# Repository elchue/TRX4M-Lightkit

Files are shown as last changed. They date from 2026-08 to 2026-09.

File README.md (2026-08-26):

## 🚙 Traxxas TRX-4M Custom Light Controller
 

Ein maßgeschneidertes, intelligentes Steuergerät (basierend auf dem **ESP32-C6**), um das **originale Traxxas TRX-4M Pro Scale Lichtkit (inkl. Lightbar)** mit 3rd-Party Fernsteuerungen (wie Flysky Noble NB4, Radiomaster, Futaba etc.) und Aftermarket-ESCs weiterverwenden zu können!

Wer seinen TRX-4M auf Brushless (z. B. Furitek) oder eine professionelle Funke umbaut, verliert normalerweise die Funktion des originalen Traxxas-Lichtsets, da dieses fest an die Traxxas ECM-2.5 Einheit gebunden ist. Dieses Projekt ersetzt die Traxxas-Elektronik als "Gehirn" für die Lichter und wertet das System mit smarten Features, Web-Konfiguration und Telemetrie-ähnlicher Auswertung extrem auf.

## ✨ Warum dieses Projekt?
Das originale TRX-4M Lichtkit nutzt adressierbare LEDs (ähnlich dem WS2812-Protokoll), die über eine serielle Datenleitung angesteuert werden. Wie genau wir die proprietären Signale entschlüsselt haben, kannst du in unserer detaillierten [Hardware & Protokoll Dokumentation (Reverse Engineering)](/docs/README.md) nachlesen.

Dieses Modul liest das Signal deines neuen Empfängers aus, berechnet die Fahrphysik und übersetzt sie in Echtzeit für das Traxxas-Lichtset. Du musst nichts abrüsten oder neu verkabeln – das Modul klinkt sich einfach als Übersetzer dazwischen!

## 🚀 Features
* **Multi-Protokoll für 3rd-Party Empfänger:** Unterstützt SBUS, iBUS und klassisches PPM. Ideal für Micro-Empfänger.
* **Smartphone Web-Interface:** Eigener WLAN-Access-Point zur einfachen Konfiguration direkt am Fahrzeug (Deutsch & Englisch). Kein PC auf dem Trail nötig!
* **Perfekte Anpassung an die Funke:**
  * **Volles Channel-Mapping:** Weise Funktionen wie Hauptlicht, Zusatzscheinwerfer und Blinker völlig frei beliebigen Empfängerkanälen zu.
  * **Auto-Trim-Funktion:** Ein Klick im Web-Interface und das Modul speichert den mechanischen Lenk-Offset (Nullpunkt) deiner Funke.
  * **Reverse-Schalter:** Die Laufrichtung jedes Kanals lässt sich direkt in der Software umkehren.
* **Erweiterte Blinker- & Licht-Logik:**
  * **Smart Auto-Cancel:** Blinker schaltet sich wie beim echten Auto ab, wenn du aus der Kurve lenkst.
  * **Blinker-Styles:** Wähle das optische Design (Classic, Soft-Off (Mazda), Soft-On (BMW), Retro Glühlampe).
  * **Regionale Licht-Profile (EU/US):** Verwandle die Optik deines Scalers mit einem Klick:
    * *EU-Style:* Klassisch getrennte Blinker (gelb) und Bremslichter (rot).
    * *US-Style Front:* Vordere Blinker glimmen dauerhaft gedimmt als orange Sidemarker (Standlicht) und pulsieren beim Blinken.
    * *US-Style Komplett:* Front-Sidemarker kombiniert mit typisch amerikanischem Heck (das rote Bremslicht blinkt im Takt, die gelben Blinker bleiben deaktiviert).
* **Adaptives Bremslicht (ESS):** Erkennt echte Vollbremsungen über den Gashebel und lässt das Bremslicht realistisch flackern. Danach schaltet sich automatisch der Warnblinker ein.
* **ESC-Kompatibilität & Fahrlogik:** Drei wählbare Profile für die perfekte Erkennung von Bremse und Rückfahrlicht:
  * *Standard:* Klassischer RC-Regler (Doppelklick für Rückwärts).
  * *Crawler (FOC):* Drag-Brake Erkennung und direkter Übergang in den Rückwärtsgang.
  * *Real-Car (Getriebe):* Manuelle Gangschaltung (Vorwärts / Rückwärts) über einen separaten AUX-Kanal für den ultimativen Scale-Realismus.
* **Standby & Parklicht:** Dimmt die Scheinwerfer nach definierter Inaktivität automatisch ab, um Strom zu sparen und Hitzestau zu vermeiden. Generelle Master-Helligkeit im Web-UI einstellbar.

## 🛠 Hardware & Verkabelung
Das Projekt läuft auf einem **Seeed Studio XIAO ESP32-C6** (oder ähnlichen, kompakten ESP32-Boards), da dieser klein genug ist, um problemlos in den TRX-4M zu passen.
* **Eingang:** Der ESP32 wird per 3-Pin-Kabel mit dem Empfänger verbunden (Strom, GND, Signal-Pin für SBUS/iBUS/PPM).
* **Ausgänge (2-Kanal System):** Die Ansteuerung der Traxxas-LEDs erfolgt über zwei getrennte Datenleitungen am ESP32.
  * **Kanal 1 (Main):** Übernimmt die komplette Basis-Fahrzeugbeleuchtung (Scheinwerfer, Rücklichter, Blinker).
  * **Kanal 2 (Aux):** Ist exklusiv für Zusatzscheinwerfer (z. B. Lightbars oder Roof-Lights) reserviert und lässt sich separat schalten.

*(Detaillierte Pin-Belegung und Schaltpläne für den Anschluss des Traxxas-Kabelbaums findest du im Wiki / in den Code-Kommentaren).*

## 💻 Installation (PlatformIO)
1. Repository klonen: 
    ``` bash
    git clone https://github.com/DEIN_NAME/trx4m-light-controller.git
    ```
2. Ordner in **VS Code** (mit PlatformIO) öffnen.
3. ESP32-C6 über USB-C anschließen.
4. Auf "Upload" klicken – PlatformIO kompiliert den Code und flasht den Chip automatisch.

## 📱 Konfiguration im Fahrzeug
1. TRX-4M einschalten. Der ESP32 öffnet ein WLAN-Netzwerk (z.B. ProScale-Config).
2. Smartphone verbinden und [http://192.168.4.1](http://192.168.4.1) im Browser öffnen.
3. Kanäle zuweisen, Blinker-Verhalten wählen und ggf. die Lenkung über den "Auto-Trim"-Button exakt nullen.
4. Speichern, Neustart abwarten – fertig für den Trail!

## 📄 Lizenz
Dieses Projekt ist unter der GNU General Public License v3.0 (GPLv3) lizenziert. Der Code ist Open Source. Details siehe LICENSE-Datei.

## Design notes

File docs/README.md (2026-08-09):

# TRX-4M Pro Scale Lichtsystem - Reverse Engineering

Dieses Repository enthält die Hardware-Zuordnung und Logik, um das proprietäre Traxxas TRX-4M Pro Scale Lichtsystem (Light Kit) sowie das originale Zubehör (Anhänger-Beleuchtung, Lightbars) mit eigenen Mikrocontrollern (z. B. ESP32, Arduino, SAMD21) und Standard-RC-Empfängern (wie Flysky iBUS) zu steuern.

## Hardware-Aufbau und das Y-Kabel-Prinzip

Das Traxxas Lichtkabel basiert technisch auf dem **WS2811/WS2812 (NeoPixel)** Protokoll. Anstatt jedoch echte RGB-LEDs zu verbauen, die ihre Farbe wechseln können, nutzt Traxxas unsichtbare Controller-Chips auf den Platinen, die das Signal empfangen. An die drei Farbausgänge (Rot, Grün, Blau) eines einzelnen Chips hat Traxxas hardwareseitig **drei verschiedene, einfarbige LEDs** gelötet. Ein Befehl für "100% Rot" schaltet also keine rote Farbe ein, sondern aktiviert einen spezifischen Funktionsausgang (z. B. den Blinker).

### Besonderheit: Die Verkabelung am ECM-2.5
Am originalen Traxxas **ECM-2.5** (Empfänger/ESC-Einheit) wird das Datensignal teilweise über physische Y-Kabel aufgeteilt:
1. **Haupt-Lichtkit:** Steuert die vier Ecken des Fahrzeugs.
2. **Zusatzscheinwerfer:** (Lightbar + Kühlergrill) Hängen an einem Y-Kabel und lesen denselben Datenstrom wie das vordere linke Abblendlicht mit.
3. **Anhänger:** Hängt ebenfalls an einem Y-Kabel. Die Chips im Anhänger sind so konfiguriert, dass sie synchron auf die Daten der hinteren Fahrzeugbeleuchtung (Chip 2 und 3) reagieren.

## Die LED-Matrix (Hardware Mapping)

Das gesamte System lässt sich im Code wie ein Strang aus **4 NeoPixel-Chips** (Index 0 bis 3) ansteuern. Die Helligkeit der Lampen kann über PWM-Werte (0 = Aus, 255 = Hell) stufenlos gedimmt werden.

| Chip Index | Farb-Kanal im Code | Funktion am Fahrzeug | Funktion am Anhänger |
| :--- | :--- | :--- | :--- |
| **Chip 0** | Rot | Blinker vorne Links | - |
| **Chip 0** | Grün | Tagfahrlicht Links | - |
| **Chip 0** | Blau | Abblendlicht Links + Zusatzscheinwerfer* | - |
| **Chip 1** | Rot | Blinker vorne Rechts | - |
| **Chip 1** | Grün | Tagfahrlicht Rechts | - |
| **Chip 1** | Blau | Abblendlicht Rechts | - |
| **Chip 2** | Rot | Blinker hinten Rechts | Blinker Rechts (rot) |
| **Chip 2** | Grün | Rückfahrlicht Rechts (weiß) | Rückfahrlicht Rechts |
| **Chip 2** | Blau | Rücklicht / Bremslicht Rechts | Bremslicht Rechts |
| **Chip 3** | Rot | Blinker hinten Links | Blinker Links (rot) |
| **Chip 3** | Grün | Rückfahrlicht Links (weiß) | Rückfahrlicht Links |
| **Chip 3** | Blau | Rücklicht / Bremslicht Links | Bremslicht Links |

*\*Hinweis zu den Zusatzscheinwerfern: Da diese über ein Y-Kabel fest mit dem blauen Kanal von Chip 0 gekoppelt sind, leuchten sie im Werkszustand immer synchron mit dem Abblendlicht auf.*

## Modding-Potenzial: Unabhängige Steuerung

Da das Traxxas ECM-2.5 die Stränge per Y-Kabel zusammenschließt, sind Anhänger und Lightbar im Originalzustand an die Hauptbeleuchtung gekoppelt. 

Wenn man das System mit einem eigenen Mikrocontroller steuert, können die Y-Kabel entfernt und die Komponenten an **separate GPIO-Pins** des Mikrocontrollers (z. B. 3 getrennte NeoPixel-Instanzen in der Software) angeschlossen werden. 
Dies ermöglicht völlig neue Funktionen, wie zum Beispiel:
* Zusatzscheinwerfer (Dach/Grill) unabhängig vom Abblendlicht per Fernsteuerung schalten.
* Anhängerbeleuchtung abweichend vom Zugfahrzeug steuern (z. B. Warnblinker nur am Anhänger).

## Programmierung (Beispiel)

Zur Ansteuerung kann jede handelsübliche Bibliothek für adressierbare LEDs genutzt werden (z. B. `Adafruit_NeoPixel` oder `FastLED`).

Um das Bremslicht hinten links am Fahrzeug (und zeitgleich am Anhänger, falls per Y-Kabel verbunden) auf 100% Helligkeit einzuschalten, wird der "Blaue" Kanal von Chip 3 angesteuert:
`strip.setPixelColor(3, 0, 0, 255)`

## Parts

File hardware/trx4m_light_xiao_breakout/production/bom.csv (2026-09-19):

Designator | Footprint | Quantity | Value | LCSC Part #
C1, C4 | CP_EIA-7343-20_Kemet-V | 2 | 470µF | C49332972
C2, C5 | 0805 | 2 | 100nF | C28233
C3 | 0805 | 1 | 10µF | C15850
J1, J2, J3 | PinHeader_1x03_P2.54mm_Vertical | 3 | Conn_01x03
L1 | L_Ferrocore_DLG-0403 | 1 | 4.7µH | C2879693
R1 | 0805 | 1 | 330R | C17630
R2 | 0805 | 1 | R330 | C17630
SW1 | SW_Tactile_SPST_NO_Straight_CK_PTS636Sx25SMTRLFS | 1 | SW_Push | C2689642
U1 | XIAO-14P-Add-On | 1 | XIAO-ESP32-C6-SMD
U2 | VSSOP-8_2.3x2mm_P0.5mm | 1 | 74LVC2T45DC | C15741
U3 | TSOT-23-6 | 1 | AP63205WU | C2071056

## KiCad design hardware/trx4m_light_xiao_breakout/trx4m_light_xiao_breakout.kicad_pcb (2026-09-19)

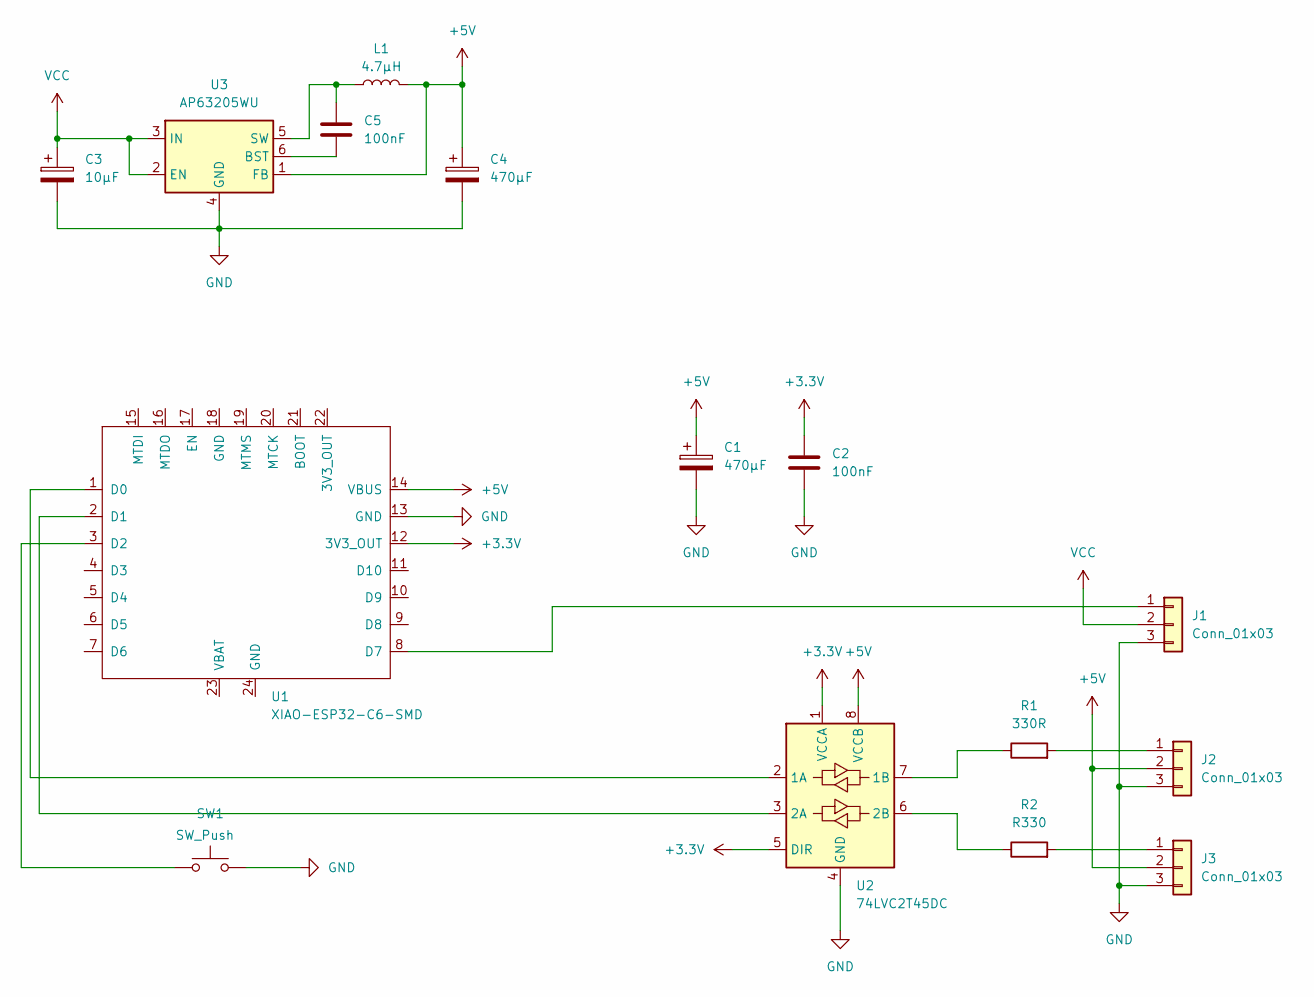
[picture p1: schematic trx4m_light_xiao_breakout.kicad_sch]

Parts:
C1, C4: 470µF; CP_EIA-7343-20_Kemet-V; LCSC C49332972
C2, C5: 100nF; C_0805_2012Metric; LCSC C28233
C3: 10µF; C_0805_2012Metric; LCSC C15850
J1, J2, J3: Conn_01x03; PinHeader_1x03_P2.54mm_Vertical
L1: 4.7µH; L_Ferrocore_DLG-0403; LCSC C2879693
R1: 330R; R_0805_2012Metric; LCSC C17630
R2: R330; R_0805_2012Metric; LCSC C17630
SW1: SW_Push; SW_Tactile_SPST_NO_Straight_CK_PTS636Sx25SMTRLFS; LCSC C2689642
U1: XIAO-ESP32-C6-SMD; XIAO-14P-Add-On
U2: 74LVC2T45DC; VSSOP-8_2.3x2mm_P0.5mm; LCSC C15741
U3: AP63205WU; TSOT-23-6; LCSC C2071056

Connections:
+3.3V: C2.1, U1.12 (3V3_OUT), U2.1 (VCCA), U2.5 (DIR)
+5V: C1.1, C4.1, J2.2, J3.2, L1.2, U1.14 (VBUS), U2.8 (VCCB), U3.1 (FB)
GND: C1.2, C2.2, C3.2, C4.2, J1.3, J2.3, J3.3, SW1.2, U1.13 (GND), U2.4 (GND), U3.4 (GND)
unnamed: J1.1, U1.8 (D7)
unnamed: J2.1, R1.2
unnamed: J3.1, R2.2
unnamed: U1.1 (D0), U2.2 (1A)
unnamed: U1.2 (D1), U2.3 (2A)
unnamed: SW1.1, U1.3 (D2)
unnamed: R1.1, U2.7 (1B)
unnamed: R2.1, U2.6 (2B)
unnamed: C5.2, U3.6 (BST)
unnamed: C5.1, L1.1, U3.5 (SW)
VCC: C3.1, J1.2, U3.2 (EN), U3.3 (IN)

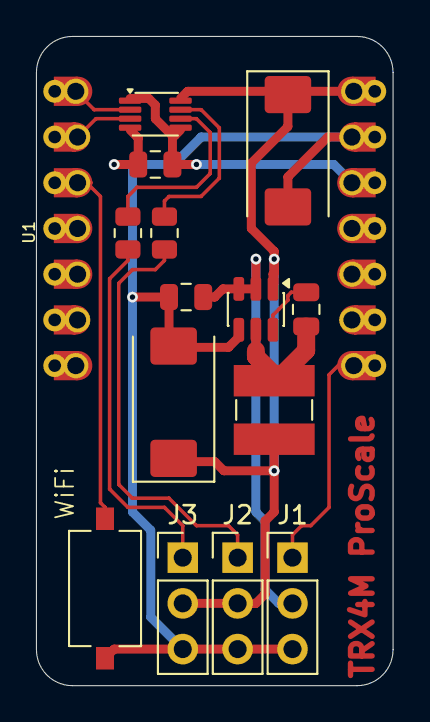
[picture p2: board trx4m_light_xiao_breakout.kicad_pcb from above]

Board: 2 copper layers, 19.8 x 36.1 mm, 15 parts (0 on the bottom side), 14 nets.

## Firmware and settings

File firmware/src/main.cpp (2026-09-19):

#include <Arduino.h>
#include "modules/globals.h"
#include "modules/rc_input.h"
#include "modules/web_config.h"
#include "modules/led_output.h"
#include "modules/drive_logic.h"

// ==========================================
// GLOBALE VARIABLEN DEKLARATION (Hier erwachen sie zum Leben)
// ==========================================
Config cfg;
uint16_t rc_channels[14] = {1500, 1500, 1500, 1500, 1500, 1500, 1500, 1500, 1500, 1500, 1500, 1500, 1500, 1500};
unsigned long last_rc_time = 0;
bool signalValid = false;

bool configMode = false;
volatile bool clientDisconnected = false;
unsigned long letzteBewegung = 0;

Adafruit_NeoPixel stripMain(NUM_LEDS_MAIN, PIN_LED_MAIN, NEO_RGB + NEO_KHZ800);
Adafruit_NeoPixel stripAux(NUM_LEDS_AUX, PIN_LED_AUX, NEO_RGB + NEO_KHZ800);

// ==========================================
// STATUS / HEARTBEAT EFFEKT (WLAN & Failsafe)
// ==========================================
void showStatusEffect(uint8_t peak_brightness) {
  float breath = (sin(millis() / 250.0) + 1.0) / 2.0; 
  uint8_t val = (uint8_t)(breath * peak_brightness);

  stripMain.setPixelColor(0, stripMain.Color(val, 0, 0));
  stripMain.setPixelColor(1, stripMain.Color(val, 0, 0));
  stripMain.setPixelColor(2, stripMain.Color(val, 0, 0));
  stripMain.setPixelColor(3, stripMain.Color(val, 0, 0));

  stripAux.setPixelColor(0, stripAux.Color(0, 0, 0));

  stripMain.show();
  stripAux.show();
}

// ==========================================
// SETUP
// ==========================================
void setup()
{
  Serial.begin(115200);
  pinMode(PIN_BTN, INPUT_PULLUP);

  // --- RF ANTENNEN LOGIK (XIAO ESP32-C6) ---
  pinMode(PIN_RF_EN, OUTPUT);
  digitalWrite(PIN_RF_EN, LOW);  // RF Enable
  pinMode(PIN_RF_SEL, OUTPUT);
  digitalWrite(PIN_RF_SEL, LOW); // Interne Antenne

  // --- USER LED LOGIK ---
  pinMode(PIN_LED, OUTPUT);
  digitalWrite(PIN_LED, LOW); // LED aus im Normalbetrieb

  // --- ANTI-FLICKER (Software Pull-Down vor LED Init) ---
  pinMode(0, OUTPUT); digitalWrite(0, LOW);
  pinMode(1, OUTPUT); digitalWrite(1, LOW);

  initLEDs();
  loadConfig();
  delay(100);

  // Fallback: Taster beim direkten Start gedrückt -> WLAN Setup
  if (digitalRead(PIN_BTN) == LOW)
  {
    configMode = true;
    digitalWrite(PIN_LED, LOW); // Status-LED an
    initWebConfig();
    return; // Das visuelle Feedback passiert ab jetzt automatisch in der loop()
  }

  // Normaler Fahrbetrieb
  Serial.println("Starte Fahrbetrieb...");
  initRC();
}

// ==========================================
// MAIN LOOP
// ==========================================
void loop()
{
  // 1. WEB CONFIG MODUS BLOCKIERT DEN REST
  if (configMode)
  {
    handleWebConfig();
    showStatusEffect(BRIGHT_DIMMED); // WLAN = Sanftes Atmen (gedimmt)
    return;
  }

  // 2. TASTER AUSWERTEN (3 Sekunden halten für Setup)
  static unsigned long btnPressStart = 0;
  static bool btnIsPressed = false;

  if (digitalRead(PIN_BTN) == LOW) 
  {
    if (!btnIsPressed) {
      btnIsPressed = true;
      btnPressStart = millis(); // Zeitstempel beim ersten Drücken merken
    } 
    else if (millis() - btnPressStart > 3000) // 3000 ms (3 Sekunden) gehalten
    { 
      Serial.println("Wechsle in WLAN Setup-Modus...");
      configMode = true;
      digitalWrite(PIN_LED, LOW); // Status-LED auf dem Board an
      initWebConfig();
      return; // Loop hier abbrechen, im nächsten Durchlauf greift Block 1
    }
  } 
  else 
  {
    btnIsPressed = false; // Taster losgelassen, Timer Reset
  }

  // 3. RC Daten aktualisieren
  updateRC();

  // 4. Kanäle auslesen
  int valSteering = 1500;
  int valThrottle = 1500;
  int valLight = 1500;
  int valAux = 1500;
  int valBlinkerMan = 1500;
  int valHazard = 1500;
  int valGear = 1500;

  // 5. Kanäle auslesen und manipulieren (Trim & Reverse)
  if (signalValid)
  {
    // --- LENKUNG (mit Trim & Reverse) ---
    if (cfg.ch_steer > 0)
    {
      valSteering = rc_channels[cfg.ch_steer - 1] + cfg.trim_steer;
      if (cfg.rev_steer) valSteering = 3000 - valSteering;
    }

    // --- GAS / BREMSE ---
    if (cfg.ch_throttle > 0)
    {
      valThrottle = rc_channels[cfg.ch_throttle - 1];
      if (cfg.rev_throttle) valThrottle = 3000 - valThrottle;
    }

    // --- HAUPTLICHT ---
    if (cfg.ch_light > 0)
    {
      valLight = rc_channels[cfg.ch_light - 1];
      if (cfg.rev_light) valLight = 3000 - valLight;
    }

    // --- ZUSATZLICHT (AUX) ---
    if (cfg.ch_aux > 0)
    {
      valAux = rc_channels[cfg.ch_aux - 1];
      if (cfg.rev_aux) valAux = 3000 - valAux;
    }

    // --- MANUELLER BLINKER ---
    if (cfg.ch_blinker_man > 0)
    {
      valBlinkerMan = rc_channels[cfg.ch_blinker_man - 1];
      if (cfg.rev_blinker_man) valBlinkerMan = 3000 - valBlinkerMan;
    }

    // --- WARNBLINKER ---
    if (cfg.ch_hazard > 0)
    {
      valHazard = rc_channels[cfg.ch_hazard - 1];
      if (cfg.rev_hazard) valHazard = 3000 - valHazard;
    }

    // --- GETRIEBE ---
    if (cfg.ch_gear > 0)
    {
      valGear = rc_channels[cfg.ch_gear - 1];
      if (cfg.rev_gear) valGear = 3000 - valGear;
    }

    // 6. Fahrlogik berechnen
    updateDriveLogic(valThrottle, valSteering, valGear);

    // 7. LEDs ansteuern!
    updateLEDs(valThrottle, valSteering, valLight, valAux, valBlinkerMan, valHazard);
  }
  else 
  {
    // FAILSAFE ANZEIGE: Wenn das RC-Signal weg ist, warnt das Fahrzeug
    showStatusEffect(BRIGHT_MAX); // Failsafe = Helles, deutliches Atmen
  }

  // 8. Debug Ausgabe
  static unsigned long lastDebug = 0;
  if (millis() - lastDebug > 200)
  {
    lastDebug = millis();
    if (signalValid)
    {
      Serial.printf("CH1:%4d CH2:%4d CH3:%4d CH4:%4d CH5:%4d CH6:%4d CH7:%4d CH8:%4d | FWD:%d REV:%d BRK:%d PRK:%d\n",
                    rc_channels[0], rc_channels[1], rc_channels[2], rc_channels[3],
                    rc_channels[4], rc_channels[5], rc_channels[6], rc_channels[7],
                    car_is_driving, car_is_reversing, car_is_braking, car_is_parked);
    }
    else
    {
      Serial.println("Failsafe aktiv...");
    }
  }
}

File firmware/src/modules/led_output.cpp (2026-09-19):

#include "led_output.h"
#include "globals.h"
#include <math.h> // Für die weichen Fade-Kurven

// Externe Zustände aus der drive_logic
extern bool car_is_driving;
extern bool car_is_reversing;
extern bool car_is_braking;
extern bool car_is_standing;
extern bool car_is_parked;

// ==========================================
// FADING HELPER
// ==========================================
uint8_t fadeTowards(uint8_t current, uint8_t target, uint8_t step) {
  if (current < target) {
    if (current + step > target) return target;
    return current + step;
  } else if (current > target) {
    if (current < step) return 0;
    if (current - step < target) return target;
    return current - step;
  }
  return current;
}

// ==========================================
// 1. HELFER-FUNKTION: BLINKER ANIMATION
// ==========================================
uint8_t getBlinkerPWM(bool active, int style, unsigned long cycle_pos)
{
  if (!active) return 0;

  if (style == 0) { // Classic
    return (cycle_pos < BLINK_INTERVAL_MS) ? BRIGHT_MAX : 0;
  }
  else if (style == 1) { // Mazda (Soft Off)
    if (cycle_pos < BLINK_INTERVAL_MS) {
      return BRIGHT_MAX;
    } else {
      unsigned long off_pos = cycle_pos - BLINK_INTERVAL_MS;
      float fade_out_ms = BLINK_INTERVAL_MS * 0.6;
      if (off_pos < fade_out_ms) {
        float p = off_pos / fade_out_ms;
        return (uint8_t)(BRIGHT_MAX * (1.0 - p));
      }
      return 0;
    }
  }
  else if (style == 2) { // BMW (Soft-On)
    if (cycle_pos < BLINK_INTERVAL_MS) {
      float p = (float)cycle_pos / BLINK_INTERVAL_MS; 
      float curve = p * p; 
      return (uint8_t)(BRIGHT_MAX * curve);
    }
    return 0;
  }
  else if (style == 3) { // Retro (Glühlampen-Fade)
    const float heat_up_ms = 80.0;
    const float cool_down_ms = 150.0;
    if (cycle_pos < BLINK_INTERVAL_MS) {
      if (cycle_pos < heat_up_ms) {
        float p = cycle_pos / heat_up_ms;
        return (uint8_t)(BRIGHT_MAX * (1.0 - pow(1.0 - p, 3)));
      }
      return BRIGHT_MAX;
    } else {
      unsigned long off_pos = cycle_pos - BLINK_INTERVAL_MS;
      if (off_pos < cool_down_ms) {
        float p = off_pos / cool_down_ms;
        return (uint8_t)(BRIGHT_MAX * pow(1.0 - p, 2));
      }
      return 0;
    }
  }
  return (cycle_pos < BLINK_INTERVAL_MS) ? BRIGHT_MAX : 0;
}

// ==========================================
// 2. INITIALISIERUNG
// ==========================================
void initLEDs()
{
  stripMain.begin();
  stripAux.begin();

  int mb = (cfg.master_brightness == 0) ? 100 : cfg.master_brightness;
  uint8_t mapped_bright = map(mb, 0, 100, 0, 255);

  stripMain.setBrightness(mapped_bright);
  stripAux.setBrightness(mapped_bright);

  stripMain.clear();
  stripAux.clear();
  stripMain.show();
  stripAux.show();
}

// ==========================================
// 3. HAUPT-FUNKTION: HARDWARE MAPPING
// ==========================================
void updateLEDs(int valThrottle, int valSteering, int valLight, int valAux, int valBlinkerMan, int valHazard)
{
  // STATISCHE VARIABLEN FÜR SOFT-FADING
  static uint8_t cur_front_g_left = 0;
  static uint8_t cur_front_g_right = 0;
  static uint8_t cur_front_b = 0;
  static uint8_t cur_rear_b_left = 0;
  static uint8_t cur_rear_b_right = 0;
  static uint8_t cur_aux_b = 0;

  const uint8_t FADE_STEP = 6; 

  // ==========================================
  // 1. ESS-LOGIK (Adaptive Brake Light)
  // ==========================================
  static bool ess_was_hard_braking = false; 
  static bool ess_hazard_active = false;
  static unsigned long ess_stand_timer = 0;

  if (cfg.ess_active) {
    const int ess_threshold = (500 * ESS_THRESHOLD_PERCENT) / 100;
    bool is_hard_brake = (car_is_braking && (abs(valThrottle - 1500) > ess_threshold));
    
    if (is_hard_brake) {
      ess_was_hard_braking = true;
      ess_hazard_active = false;
      ess_stand_timer = millis();
    }
    else if (car_is_braking && ess_was_hard_braking) {
      ess_stand_timer = millis();
    }
    else if (ess_was_hard_braking && car_is_standing) {
      if (millis() - ess_stand_timer > 1000) {
        ess_hazard_active = true;
        ess_was_hard_braking = false; 
      }
    }
    if (car_is_driving || car_is_reversing) {
      ess_hazard_active = false;
      ess_was_hard_braking = false;
    }
  } else {
    ess_hazard_active = false;
    ess_was_hard_braking = false;
  }

  // ==========================================
  // 2. BLINKER TRIGGER
  // ==========================================
  bool blink_left_active = false;
  bool blink_right_active = false;

  if (cfg.mode_blinker == 0) {
    if (valSteering < (1500 - STICK_BLINK_THRESH)) blink_left_active = true;
    if (valSteering > (1500 + STICK_BLINK_THRESH)) blink_right_active = true;
  }
  else if (cfg.mode_blinker == 1 || cfg.mode_blinker == 2) {
    static int blink_state = 0;
    static int last_blk_man = 1500;
    static int last_steer = 1500;

    bool steer_left = (valSteering < (1500 - STICK_BLINK_THRESH));
    bool steer_right = (valSteering > (1500 + STICK_BLINK_THRESH));
    bool steer_center = (valSteering > 1400 && valSteering < 1600);
    bool trigger_left = false;
    bool trigger_right = false;

    if (cfg.mode_blinker == 1 && car_is_standing) {
      if (steer_left && !(last_steer < (1500 - STICK_BLINK_THRESH))) trigger_left = true;
      if (steer_right && !(last_steer > (1500 + STICK_BLINK_THRESH))) trigger_right = true;
    }
    if (cfg.mode_blinker == 2 && cfg.ch_blinker_man > 0) {
      if (valBlinkerMan < 1300 && last_blk_man >= 1300) trigger_left = true;
      if (valBlinkerMan > 1700 && last_blk_man <= 1700) trigger_right = true;
    }
    last_steer = valSteering;
    last_blk_man = valBlinkerMan;

    if (trigger_left) { blink_state = (blink_state == 1 || blink_state == 2) ? 0 : 1; }
    if (trigger_right) { blink_state = (blink_state == 3 || blink_state == 4) ? 0 : 3; }

    if (blink_state == 1) {
      if (steer_left && !car_is_standing) blink_state = 2;
      else if (steer_right) blink_state = 0;
    } else if (blink_state == 2) {
      if (steer_center) blink_state = 0;
    } else if (blink_state == 3) {
      if (steer_right && !car_is_standing) blink_state = 4;
      else if (steer_left) blink_state = 0;
    } else if (blink_state == 4) {
      if (steer_center) blink_state = 0;
    }

    blink_left_active = (blink_state == 1 || blink_state == 2);
    blink_right_active = (blink_state == 3 || blink_state == 4);
  }

  if ((cfg.ch_hazard > 0 && valHazard > 1500) || ess_hazard_active) {
    blink_left_active = true;
    blink_right_active = true;
  }

  bool any_blinker_active = (blink_left_active || blink_right_active);
  static unsigned long blink_start_time = 0;
  static bool was_active_last_frame = false;

  if (any_blinker_active && !was_active_last_frame) blink_start_time = millis();
  was_active_last_frame = any_blinker_active;
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

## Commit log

2026-08-09 Revise README for TRX-4M Lichtsystem details
    Updated README to provide detailed information on the Traxxas TRX-4M Pro Scale Lichtsystem, including hardware mapping, wiring principles, and programming examples.
2026-08-26 move to docs
    Added detailed documentation for the TRX-4M Pro Scale Lichtsystem, including hardware mapping, wiring principles, and modding potential.
2026-09-19 Add firmware, KiCad hardware v1
    [bom.csv, designators.csv, positions.csv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]
2026-10-08 Simplify drive logic activity check
    Removed steering condition from drive logic check.

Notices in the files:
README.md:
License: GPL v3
